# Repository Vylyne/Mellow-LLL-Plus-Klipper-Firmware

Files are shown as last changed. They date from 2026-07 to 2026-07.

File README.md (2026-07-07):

`src/buffer.c` is firmware — it gets compiled and flashed to the buffer board's own MCU (Installation Steps 0–6 below). `klippy_extras/` and `macros/` are host-side — they run as part of Klippy on your Klipper host (Pi/SBC) and only need `install.sh` (no compiling or flashing).

---

## Installation

> Done from your Klipper host (e.g. a Raspberry Pi). Commands assume `~/klipper` and `~/katapult` ([Arksine/katapult](https://github.com/Arksine/katapult)) are cloned, the Klipper build toolchain is installed, and `dfu-util` is available (`sudo apt install dfu-util`).

### Step 0 — Find your buffer & power it

Connect the buffer's USB to the host **and** give it **24 V on VIN** (the motor needs it; the firmware configures the TMC at first boot, so 24 V must be present then).

List USB serial devices to identify the board and note your **unique chip ID** (you'll reuse it in `printer.cfg`):

```bash
ls /dev/serial/by-id/
# e.g. usb-Klipper_stm32f072xb_3C003A...3720-if00   (or a Mellow / katapult id)
#                            └──────── your XXXXXX ────────┘
```

### Step 1 — Enter DFU mode (to install Katapult)

On the buffer board: **hold BOOT**, tap **RESET**, release **RESET**, then release **BOOT**. Confirm (needs `sudo`):

```bash
sudo dfu-util -l
# → Found DFU: [0483:df11] ... name="@Internal Flash  /0x08000000/064*0002Kg"
```

### Step 2 — Back up the existing firmware (recommended)

```bash
sudo dfu-util -a 0 -d 0483:df11 -U ~/lll_backup_flash.bin       -s 0x08000000:0x20000
sudo dfu-util -a 1 -d 0483:df11 -U ~/lll_backup_optionbytes.bin            # option bytes
```

### Step 3 — Build & flash Katapult (one-time bootloader)

Katapult lets you flash all **future** updates over USB without opening the case.

```bash
cd ~/katapult
make menuconfig
```

- Micro-controller Architecture: **STMicroelectronics STM32**
- Processor model: **STM32F072**
- Clock Reference: **8 MHz crystal**
- Communication interface: **USB (on PA11/PA12)**
- Application start offset: **8 KiB**
- Support bootloader entry on rapid double click of reset: **OFF** ⚠️ *(the LLL Plus has no usable reset button; leaving this ON makes the board fail to enumerate)*

```bash
make clean && make
# board still in DFU (Step 1); flash with mass-erase so no stale app remains:
sudo dfu-util -a 0 -d 0483:df11 -D out/katapult.bin -s 0x08000000:force:mass-erase:leave
```

Re-plug USB and confirm Katapult enumerates:

```bash
ls /dev/serial/by-id/
# → usb-katapult_stm32f072xb_XXXXXX-if00
```

### Step 4 — Add this firmware to Klipper

```bash
cp src/buffer.c ~/klipper/src/buffer.c
```

Add **one line** to `~/klipper/src/Makefile` (only compiled for the F072 buffer, never for your main board):

```make
src-$(CONFIG_MACH_STM32F072) += buffer.c
```

> ⚠️ This line is reverted by `git pull` on the Klipper tree — re-add it after updating Klipper. `buffer.c` itself is untracked and survives.

### Step 5 — Build Klipper

> ⚠️ `make menuconfig` overwrites `~/klipper/.config`. If you build other MCUs (your main board, toolhead…) from this same tree, **back up its config first** and restore it afterwards:
> ```bash
> cp ~/klipper/.config ~/klipper/.config.mainboard   # backup
> # ...build & flash the buffer...
> cp ~/klipper/.config.mainboard ~/klipper/.config    # restore later
> ```

```bash
cd ~/klipper
make menuconfig
```

- Micro-controller Architecture: **STMicroelectronics STM32**
- Processor model: **STM32F072**
- Bootloader offset: **8 KiB bootloader** *(must match Katapult)*
- Clock Reference: **8 MHz crystal**
- Communication interface: **USB (on PA11/PA12)**

```bash
make clean && make
```

### Step 6 — Flash Klipper over USB (via Katapult)

```bash
~/klippy-env/bin/python3 ~/katapult/scripts/flashtool.py \
  -f ~/klipper/out/klipper.bin \
  -d /dev/serial/by-id/usb-katapult_stm32f072xb_XXXXXX-if00
```

> Use the **klippy-env** Python — it has `pyserial` (the system Python usually doesn't). After flashing, the board re-enumerates as `usb-Klipper_stm32f072xb_XXXXXX-if00`.

### Step 7 — printer.cfg

```ini
[mcu LLL_PLUS]
serial: /dev/serial/by-id/usb-Klipper_stm32f072xb_XXXXXX-if00
restart_method: command

[filament_switch_sensor lll_entrance]
switch_pin: ^!LLL_PLUS:PB7
pause_on_runout: True
```

**Choosing the runout behaviour** (pick one):

- **Simplest — most setups:** `pause_on_runout: True` and nothing else. On runout Klipper runs your normal `PAUSE`, *including the park position your `[gcode_macro PAUSE]` / `[pause_resume]` already defines* (the same one your slicer pause uses). Your park position lives in your `PAUSE` macro — `pause_on_runout` calls it, so you don't repeat it here.

- **Add a notification / lights / etc.:** keep `pause_on_runout: True` and add a `runout_gcode:` — it runs **after** the pause, so use it for *extra* actions (not another pause):
```ini
  runout_gcode:
      M118 LLL Plus: filament runout — paused
  insert_gcode:
      M118 LLL Plus: filament reinserted
```

- **Fully custom routine** (your own park macro, `M600`, unload sequence…): set `pause_on_runout: False` and put your macro in `runout_gcode:`:
```ini
  pause_on_runout: False
  runout_gcode:
      MY_RUNOUT_MACRO
```

> ⚠️ Don't put a bare `PAUSE` in `runout_gcode` while `pause_on_runout: True` — it's a double pause. And `pause_on_runout`/`PAUSE` both rely on `[pause_resume]` being in your config (standard on virtually all printers).

**No motor/stepper/TMC section** — the firmware owns the motor; the host only reads `PB7`. Then `FIRMWARE_RESTART`.

### Step 8 — Host-side integration (optional)

This step adds two Klipper `extras` modules on top of the firmware above — neither is required for basic auto-feed + runout, which works fully from Step 7 alone.

```bash
./install.sh
```

This symlinks `klippy_extras/buffer_manager.py` and `klippy_extras/filament_watcher.py` into `~/klipper/klippy/extras/`, and the example config from `macros/` into `~/printer_data/config/`. Because these are symlinks, a later `git pull` on this repo updates the running modules immediately — you only need to re-run `install.sh` if new files are added to the repo, not for ordinary updates.

#### `buffer_manager` — host-commanded load/unload

Wraps `buffer_set_mode`/`buffer_query_state` from the firmware. One `[buffer_manager]` section per buffer board:

```ini
[buffer_manager LLL_PLUS]
mcu: LLL_PLUS
feed_speed_mm_s: 20.0   # measure this against your own buffer - don't derive it
                        # from the VACTUAL/RPM constants in buffer.c, since it
                        # also depends on your pulley/wheel diameter.
```

Two gcode commands become available for macros:

```gcode
BUFFER_SET_MODE BUFFER=LLL_PLUS MODE=FORWARD   ; push filament
BUFFER_SET_MODE BUFFER=LLL_PLUS MODE=BACK      ; retract filament
BUFFER_SET_MODE BUFFER=LLL_PLUS MODE=STOP      ; hold
BUFFER_SET_MODE BUFFER=LLL_PLUS MODE=AUTO      ; hand control back to the
                                                ; firmware's hall-sensor logic
BUFFER_QUERY BUFFER=LLL_PLUS                   ; report last known sensor/motor state
```

A held `FORWARD`/`BACK`/`STOP` is kept alive automatically while your macro runs (re-sent to the MCU every 250 ms); the firmware's own `timeout` watchdog means a crashed or disconnected host can't leave the motor running. Always finish a load/unload macro with `MODE=AUTO` explicitly — don't rely on the watchdog expiring as your normal hand-back path.

#### `filament_watcher` — direction-aware jam detection

Useful with any downstream motion sensor (e.g. a Mellow Fly MDM) — not specific to this buffer board, though `buffer_manager` above is one of the things it can watch for reversal-induced slack:

```ini
[filament_watcher MDM]
motion_pin: LLL_PLUS:PA5      # or wherever your MDM/encoder motion pin lives
detection_length: 3.5         # match your encoder wheel's rated segment spacing
confirm_window: 0.5           # seconds - two detections within this window before pausing

# name:backlash_mm pairs, comma separated. Each name is a printer object
# exposing get_position()/get_direction() (or find_past_position(), like
# extruder). backlash_mm is how far that source can travel after a direction
# reversal before we start counting missed-pulse distance against
# detection_length - accounts for slack/tolerance in that source's path to
# the encoder. Measure both values on your own setup; don't guess them.
position_sources: extruder:2.0, buffer_manager LLL_PLUS:5.0

# this gcode executes on first event missed motion event after grace period, intention is for logging.
warn_gcode:
    RESPOND MSG="Suspected filament clog on T0 - watching..."

runout_gcode:
    RESPOND MSG="Suspected filament clog"
    # TOOL is optional - omit it entirely on non-toolchanger setups
    _FILAMENT_JAM_DETECTED TOOL=T0
```

`confirm_window` requires two missed-pulse detections within that window before escalating to `runout_gcode` — a single stray miss just logs a warning. Both `detection_length` and every `backlash_mm` value are physical properties of your specific filament path (tube length/stiffness, encoder wheel choice, toolchanger dwell) and need measuring on your own hardware rather than copied from this example.

#### Uninstalling the host-side modules

```bash
./uninstall.sh
```

Only removes files it created as symlinks — it won't touch a real file that happens to share the name. It doesn't remove the `[include ...]` line from your `printer.cfg`, or revert the buffer board's own firmware (that's a separate flash step, see [Updating later](#updating-later-no-case-opening) in reverse — flash back a backed-up `.bin` from Step 2 if you want the board off this firmware entirely).

---

## Updating later (no case opening)

```bash
cd ~/klipper && make clean && make          # (re-add the Makefile line if a git pull removed it)
~/klippy-env/bin/python3 ~/katapult/scripts/flashtool.py \
  -f ~/klipper/out/klipper.bin \
  -d /dev/serial/by-id/usb-Klipper_stm32f072xb_XXXXXX-if00
# then FIRMWARE_RESTART
```

`flashtool` reboots the running app into Katapult over USB automatically — you can target the **Klipper** serial directly, no buttons.

The host-side modules (`klippy_extras/`, `macros/`) don't need reflashing — `git pull` in this repo updates them immediately since `install.sh` symlinks rather than copies. Run `FIRMWARE_RESTART` after pulling if either module's config or code changed.

---

## TMC2208 register values

Derived directly from Mellow's firmware parameters (via the `TMCStepper` library it uses), not guessed:

| Register | Value | Notes |
|---|---|---|
| GCONF | `0x000001C4` | spreadCycle, pdn_disable, mstep_reg_select (shaft bit set for FORWARD) |
| CHOPCONF | `0x12020055` | toff=5, vsense, 64 µsteps, intpol |
| IHOLD_IRUN | `0x00010F07` | IRUN=15, IHOLD=7 (≈ `rms_current(500)` @ Rsense 0.11) |
| PWMCONF | `0xC10D0024` | pwm_autoscale |
| VACTUAL | `77575` | 260 rpm, 64 µsteps |

Speed/current can be changed in `src/buffer.c` (`SPEED_RPM`, the register values) and re-flashed.

---

## Known behavior — Mainsail shows MCU load ~100% (false positive)

Once this firmware is running, Mainsail's **MCU Load** bar for the LLL Plus may read **~100 %**. **This is a false positive — the MCU is not overloaded.**

The autonomous auto-feed task bit-bangs the TMC2208 `VACTUAL` value over a software UART. Each update is a short, tightly-timed burst (~8 ms), which inflates the per-task timing **standard deviation** that Mainsail's load indicator is built on — even though the MCU is idle the vast majority of the time.

Measured over a full print (`klippy.log` / MCU stats):

| Metric | Value | Meaning |
|---|---|---|
| `mcu_awake` | ~0.03–0.06 | awake only **~3–6 %** of the time |
| `mcu_task_avg` | ~0.4 ms | tasks are short |
| `mcu_task_stddev` | ~2.5 ms | spikes from the bit-bang `VACTUAL` bursts (~8 ms) — this is what drives the "100 %" bar |
| `send_seq` vs `receive_seq` | equal | no command backlog |
| retransmits | a few bytes over a whole print | link healthy |
| "Timer too close" / shutdowns | **0** | no real overload |

**Conclusion:** the ~100 % reading is a display artifact of the bit-bang timing jitter, not an overloaded MCU. Auto-feed, buttons and runout all keep working normally — no action needed.

---

## Status / disclaimer

Validated on **one setup** (FLY LLL Buffer Plus, STM32F072CB).

**Bench-tested & working (firmware, `src/buffer.c`):**
- Auto-feed — hall sensors driving the motor (core state machine + `VACTUAL`).
- Manual **hold** of the feed / retract buttons (KEY1 / KEY2).
- Runout on `PB7` → print pause.

**Ported faithfully from Mellow's firmware but not individually exercised here** (no hardware/wiring to trigger them on this setup): mainboard signal control (`PB5`/`PB6`), the buttons' single-/double-click side-effects (EXT pin output, pause toggle), and the 60 s jam timeout.

**Host-side modules (`klippy_extras/buffer_manager.py`, `klippy_extras/filament_watcher.py`) are newer and not yet hardware-validated.** The host-commanded mode override and its watchdog fallback are implemented against the firmware commands above but haven't been exercised through a real load/unload cycle yet. The jam-detection backlash/grace logic depends on `detection_length`, `confirm_window`, and every `backlash_mm`/`feed_speed_mm_s` value being measured on real hardware rather than left at example defaults — treat the example config values as starting points, not calibrated numbers.

Pins and register values are specific to this board.

**⚠️ No warranty — use at your own risk.** This is experimental, community firmware provided **AS-IS, with NO WARRANTY of any kind** (see the [GPL-3.0](LICENSE) license — *Disclaimer of Warranty* §15 and *Limitation of Liability* §16). Flashing MCU firmware **can brick the board or damage hardware**. You assume **all** risk; the author accepts **no liability** for any damage, bricked board, failed/ruined print, or other loss. **Back up your existing firmware first** (Step 2) and make sure you understand each step before running it.

## Credits

- **[Fly3DTeam / Mellow](https://github.com/Fly3DTeam/Buffer)** — original FLY Buffer firmware & hardware (state machine ported from their open source).
- **[Nitrooxyde/Mellow-LLL-Plus-Klipper-Firmware](https://github.com/Nitrooxyde/Mellow-LLL-Plus-Klipper-Firmware)** — source for the autonomous smart-buffer auto-feed Klipper firmware this project builds on.
- **[Klipper](https://github.com/Klipper3d/klipper)** — MCU firmware framework.
- **[Katapult](https://github.com/Arksine/katapult)** — USB bootloader.
- Community Klipper integrations: [river29](https://github.com/river29/Mellow-LLLBufferPLUS-klipper), [ss1gohan13](https://github.com/ss1gohan13/BufferPLUS-klipper).

## License

[GPL-3.0](LICENSE) — derived from GPL-3.0 sources (Fly3DTeam/Buffer, Klipper).

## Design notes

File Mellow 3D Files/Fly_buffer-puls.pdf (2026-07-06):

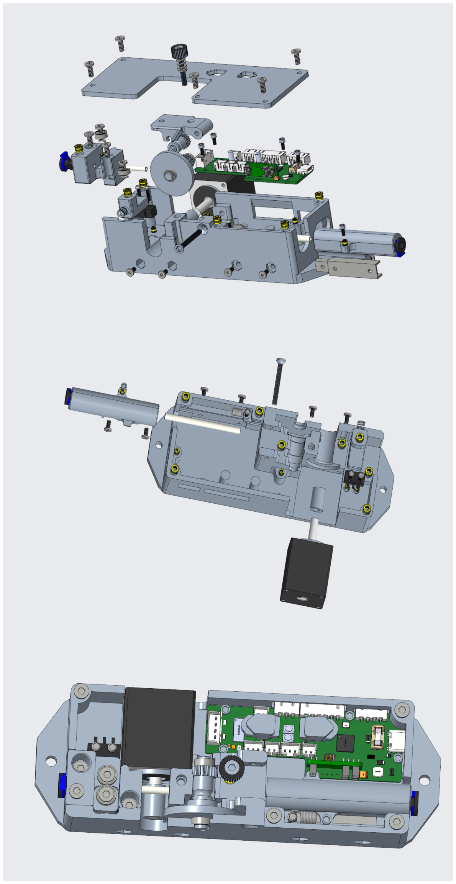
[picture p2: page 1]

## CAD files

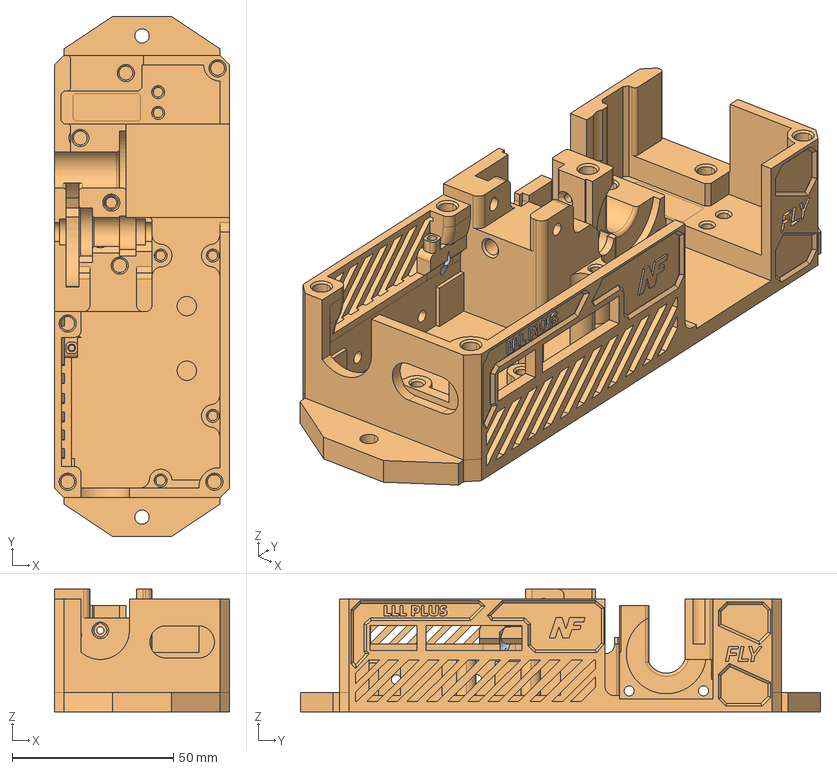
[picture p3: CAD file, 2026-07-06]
Mellow 3D Files/STEP files/Main Body.stp
54.2 x 161.0 x 38.0 mm

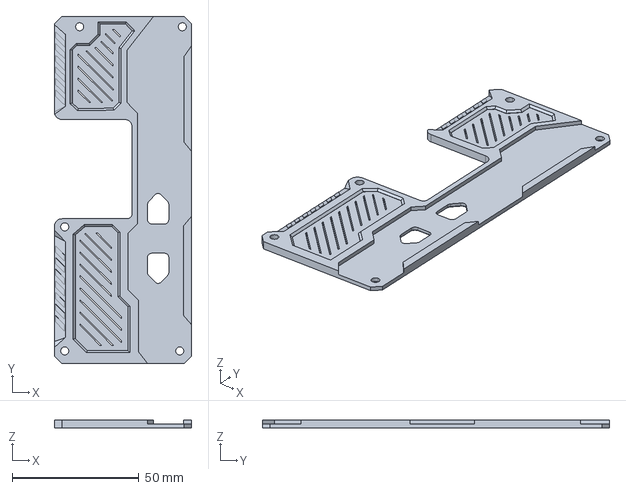
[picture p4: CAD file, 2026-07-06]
Mellow 3D Files/STEP files/Main Cover.stp
54.2 x 137.0 x 3.03 mm

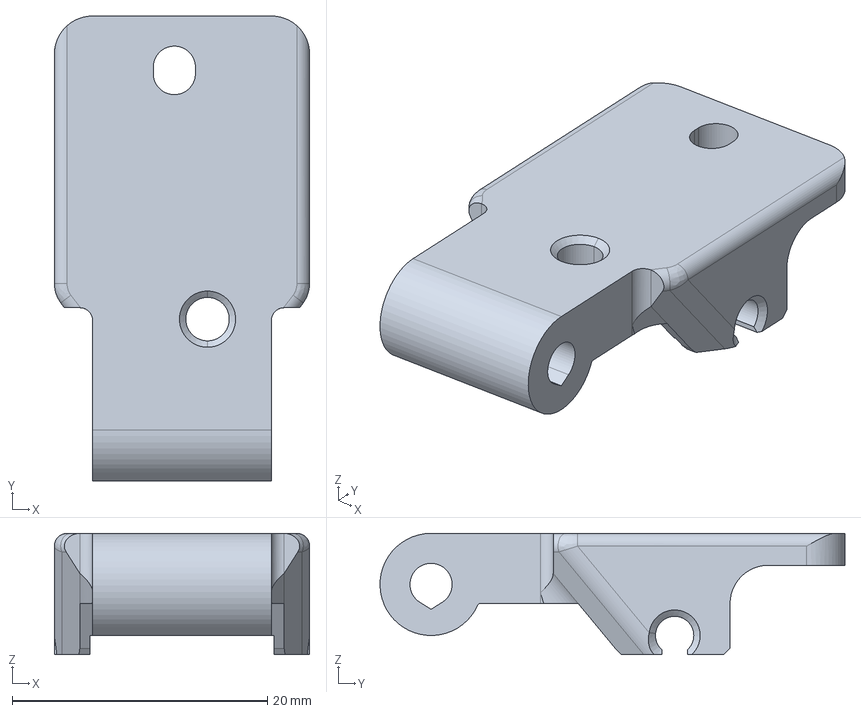
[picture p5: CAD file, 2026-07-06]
Mellow 3D Files/STEP files/Idler Tensioner.stp
20.0 x 36.4 x 9.50 mm

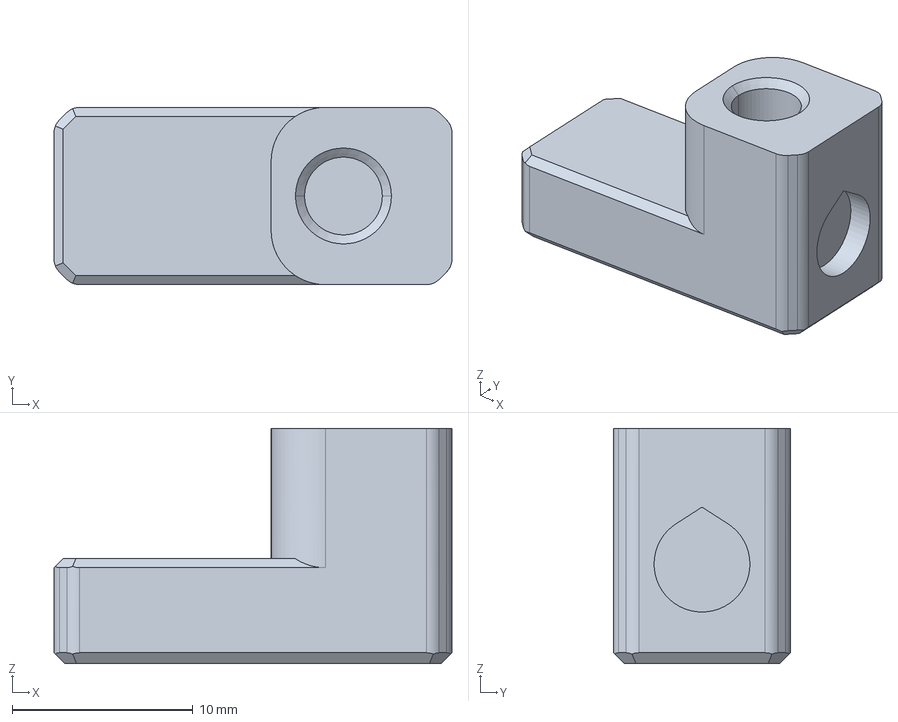
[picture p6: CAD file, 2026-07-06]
Mellow 3D Files/STEP files/Enterance Swtich Lever.stp
22.0 x 9.80 x 13.0 mm

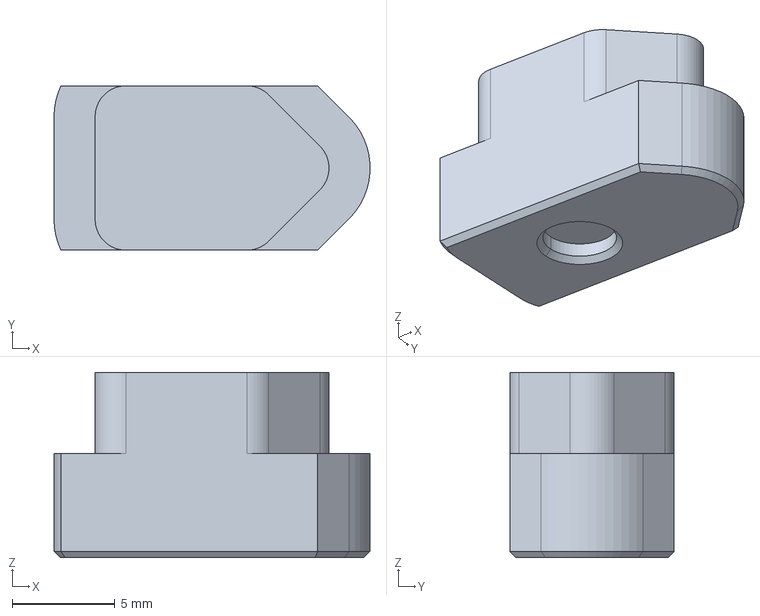
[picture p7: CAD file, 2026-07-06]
Mellow 3D Files/STEP files/Button.x2.stp
15.4 x 8.00 x 9.00 mm

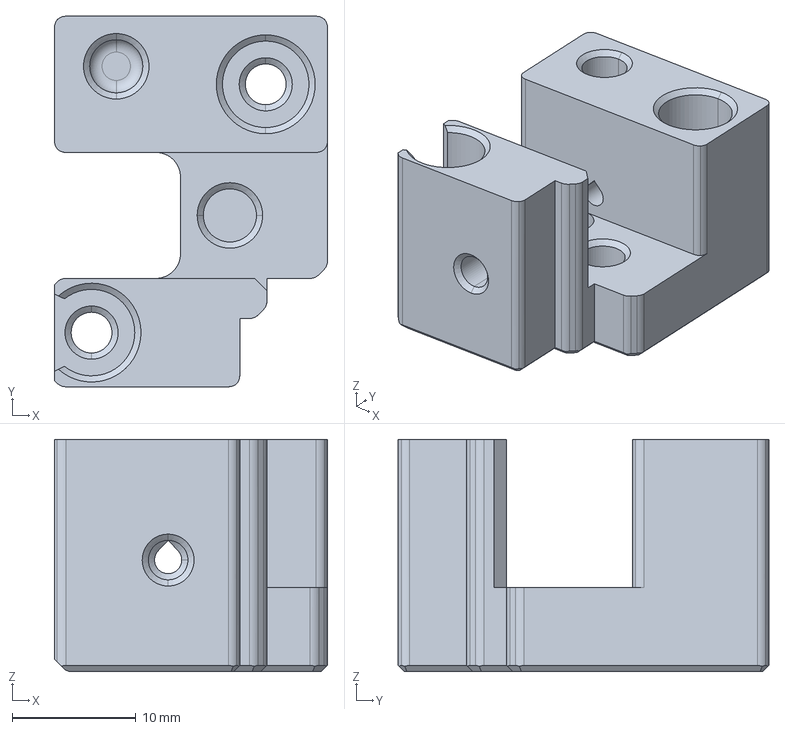
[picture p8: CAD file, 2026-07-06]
Mellow 3D Files/STEP files/Enterance Block.stp
22.1 x 30.0 x 18.8 mm

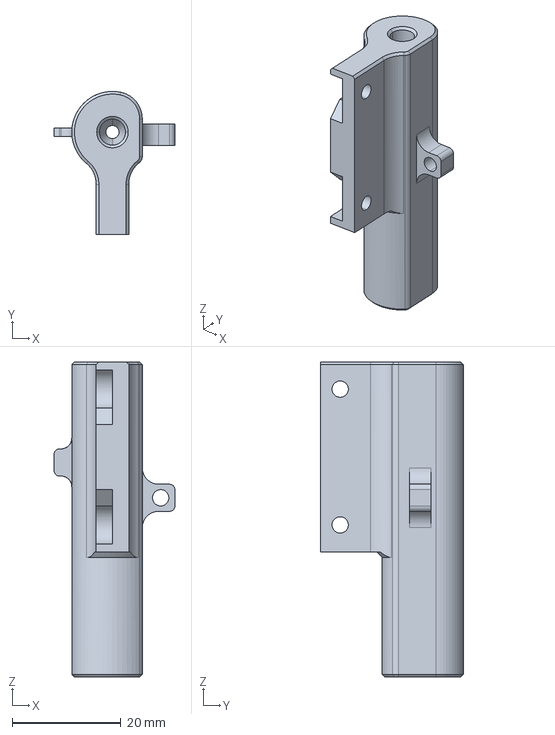
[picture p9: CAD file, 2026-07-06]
Mellow 3D Files/STEP files/Buffer Tube (slider).stp
22.2 x 26.4 x 58.0 mm

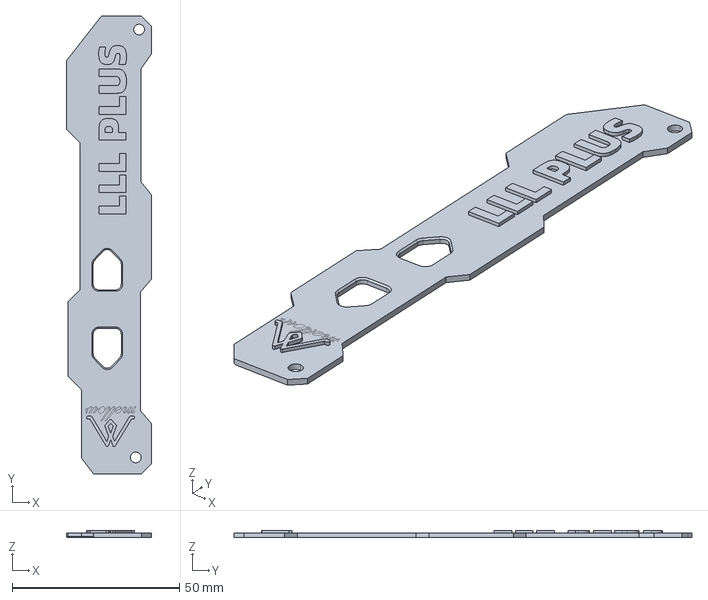
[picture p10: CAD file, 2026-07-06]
Mellow 3D Files/STEP files/Colour Plate.stp
25.4 x 137.0 x 2.17 mm

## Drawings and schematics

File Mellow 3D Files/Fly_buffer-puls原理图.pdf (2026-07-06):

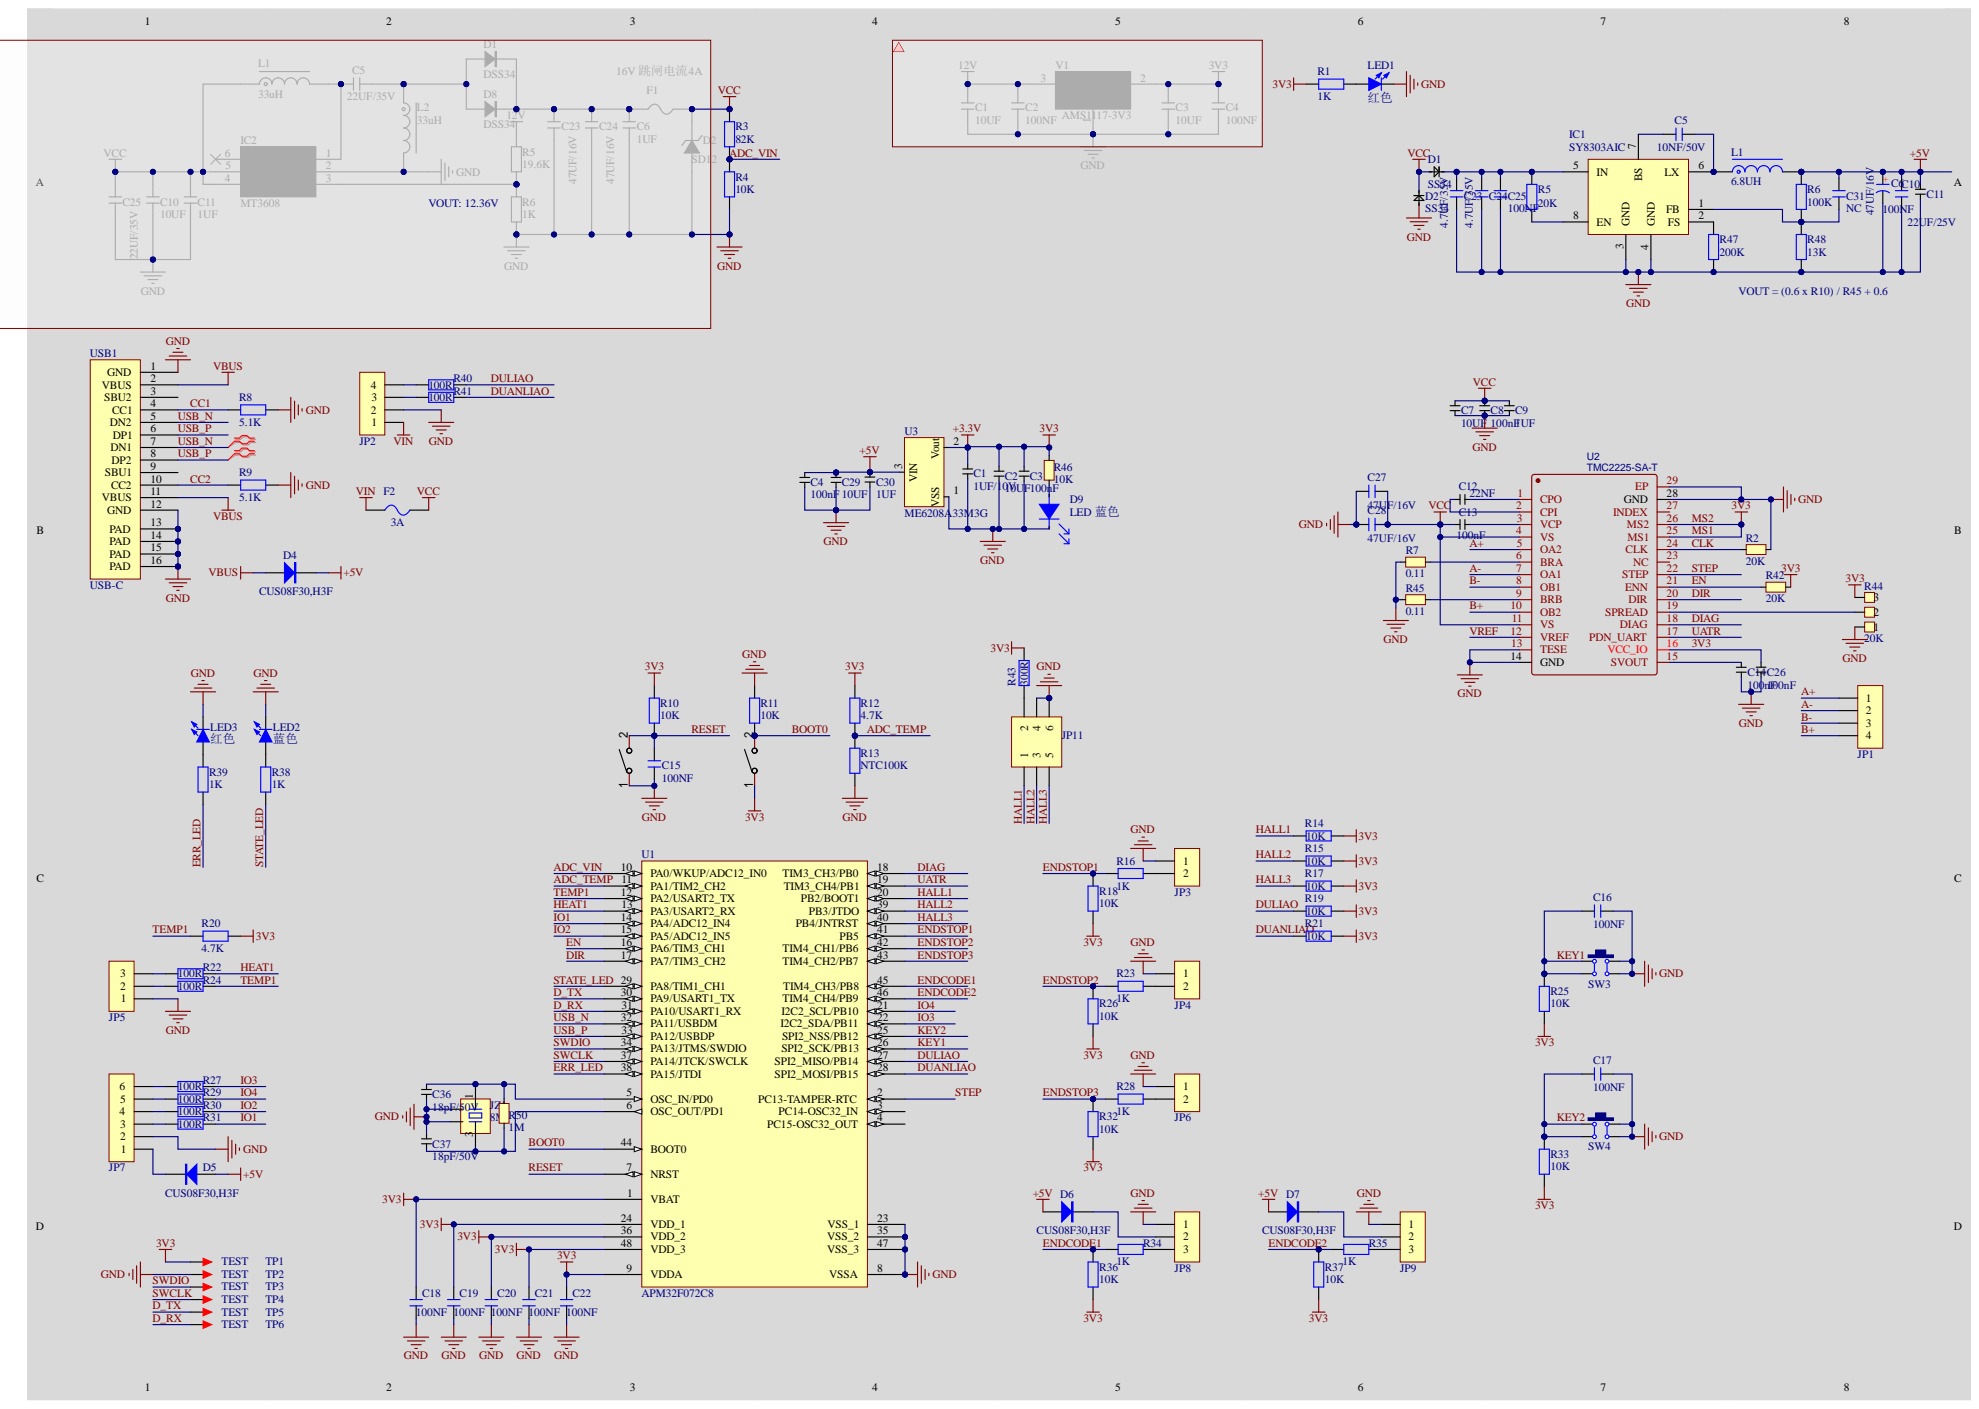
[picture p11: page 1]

VDD_1 24
VDD_2 36
VDD_3 48

VDDA 9

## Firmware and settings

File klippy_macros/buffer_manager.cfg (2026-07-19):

[gcode_macro LOAD_FILAMENT]
gcode:
    {% set tool = params.TOOL|default("T" ~ printer.toolchanger.tool_number)|upper %}
    {% set buffer = namespace(name="") %}
    {% for key in printer %}
        {% if key.startswith("buffer_manager ") %}
            {% if "T" ~ printer[key].tool == tool %}
                {% set buffer.name = key %}
            {% endif %}
        {% endif %}
    {% endfor %}
    {% if not buffer.name %}
        { action_raise_error("LOAD_FILAMENT: unknown tool '%s' (no %s)" % (tool, buffer.name)) }
    {% endif %}
    BUFFER_LOAD BUFFER={buffer.name.removeprefix("buffer_manager ").strip()} TIMEOUT=60000
    _BUFFER_JOB_POLL TOOL={tool} BUFFER={buffer.name} JOB=LOAD

[gcode_macro UNLOAD_FILAMENT]
gcode:
    {% set tool = params.TOOL|default("T" ~ printer.toolchanger.tool_number)|upper %}
    {% set buffer = namespace(name="") %}
    {% for key in printer %}
        {% if key.startswith("buffer_manager ") %}
            {% if "T" ~ printer[key].tool == tool %}
                {% set buffer.name = key %}
            {% endif %}
        {% endif %}
    {% endfor %}
    {% if not buffer.name %}
        { action_raise_error("UNLOAD_FILAMENT: unknown tool '%s' (no %s)" % (tool, buffer.name)) }
    {% endif %}
    BUFFER_UNLOAD BUFFER={buffer.name.removeprefix("buffer_manager ").strip()} TIMEOUT=60000
    _BUFFER_JOB_POLL TOOL={tool} BUFFER={buffer.name} JOB=UNLOAD

[gcode_macro _BUFFER_JOB_POLL]
gcode:
    {% set tool = params.TOOL %}
    {% set job = params.JOB %}
    {% set buffer = printer[params.BUFFER] %}
    {% if buffer.job_pending %}
        G4 P250
        _BUFFER_JOB_POLL TOOL={tool} BUFFER={params.BUFFER} JOB={job}
    {% else %}
        _BUFFER_JOB_RESULT TOOL={tool} JOB={job} STATUS={buffer.last_result_status}
    {% endif %}

[gcode_macro _BUFFER_JOB_RESULT]
gcode:
    {% set tool = params.TOOL %}
    {% set job = params.JOB %}
    {% set status = params.STATUS|int %}
    {% set labels = {0: "OK", 1: "STALLED", 2: "TIMEOUT", 3: "INTERRUPTED"} %}
    {% set label = labels.get(status, "UNKNOWN") %}
    {% if status == 0 %}
        RESPOND MSG="{job} complete: {tool}"
        # TODO: KNOMI success indication - stub. Wire up once KNOMI_CMD
        # gains a per-tool "job complete" state, e.g.:
        #   KNOMI_CMD:{tool} JOB_OK
    {% else %}
        RESPOND MSG="{job} FAILED on {tool}: {label}"
        # TODO: KNOMI failure indication - stub. Wire up once KNOMI_CMD
        # gains a per-tool "job failed" state, e.g.:
        #   KNOMI_CMD:{tool} JOB_FAIL REASON={label}
    {% endif %}

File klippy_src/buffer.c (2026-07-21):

// LLL Buffer Plus - autonomous auto-feed task for Klipper MCU firmware
//
// Ports the state machine from Mellow's standalone firmware
// (Fly3DTeam/Buffer, lib/buffer/buffer.cpp) INTO Klipper MCU firmware, as
// an autonomous task. The board remains a normal Klipper MCU (the host
// reads PB7 via [filament_switch_sensor]) AND drives the buffer motor on
// its own.
//
// ADDED file (does not modify any existing Klipper file) -> survives git pull.
//
// Convention taken VERBATIM from buffer.cpp / buffer.h:
//   photo sensor: obstructed = 1, not obstructed = 0 (direct GPIO readback, NO inversion!)
//   endstop_3/filament switch (PB7): Normally Closed, Filament Present = 0, No Filament = 1
//   buttons: normally closed, pressed = 0, released = 1
//   HALL3 (PB4) obstructed -> Forward (feed)   [pos1]
//   HALL2 (PB3) obstructed -> Stop             [pos2]
//   HALL1 (PB2) obstructed -> Back (retract)   [pos3]
//
// ONLY change vs. the standalone: button hold is handled event-driven
// (non-blocking) instead of the original blocking while() loop, because
// blocking for seconds would break Klipper host comms. Behavior is
// otherwise identical.
//
// This file may be distributed under the terms of the GNU GPLv3 license.

#include "autoconf.h"   // CONFIG_CLOCK_FREQ
#include "board/gpio.h" // gpio_in_setup / gpio_out_setup
#include "board/misc.h" // timer_read_time
#include "command.h"    // DECL_COMMAND / sendf
#include "sched.h"      // DECL_TASK / DECL_INIT

// ------------------------------------------------------------------
// Pins (Klipper encoding: GPIO(PORT,NUM) = (PORT-'A')*16 + NUM)
// ------------------------------------------------------------------
#define GPIO(PORT, NUM) (((PORT) - 'A') * 16 + (NUM))

#define HALL1_PIN GPIO('B', 2)             // Optical sensor 3 -> pos3 -> back limit, retract.
#define HALL2_PIN GPIO('B', 3)             // Optical sensor 2 -> pos2 -> mid, don't push or pull.
#define HALL3_PIN GPIO('B', 4)             // Optical sensor 1 -> pos1 -> forward limit, feed.
#define FIL_PIN GPIO('B', 7)               // ENDSTOP_3 / filament entry switch.
#define KEY_INTERNAL_RETRACT GPIO('B', 13) // KEY1 Retract (retract)
#define KEY_INTERNAL_FEED GPIO('B', 12)    // KEY2 Feed (feed)
#define KEY_EXTERNAL_RETRACT GPIO('A', 2)  // Exposed 3 pin header, external retract button
#define KEY_EXTERNAL_FEED GPIO('A', 3)     // Exposed 3 pin header, external feed button
#define KEY_EXTERNAL_UNLOAD GPIO('B', 10)  // Exposed 3 pin header, triggers UNLOAD job
#define KEY_EXTERNAL_LOAD GPIO('B', 11)    // Exposed 3 pin header, triggers LOAD job
#define MDM_FILAMENT_PIN GPIO('A', 4)      // MDM filament presence sensor
#define MDM_MOTION_PIN GPIO('A', 5)        // MDM motion sensor (encoder pulse)
#define FRONT_SIG_PIN GPIO('B', 5)         // mainboard "advance" signal (active low)
#define BACK_SIG_PIN GPIO('B', 6)          // mainboard "retract" signal (active low)
#define EXT1_PIN GPIO('C', 13)             // EXTENSION_PIN1
#define EXT2_PIN GPIO('C', 14)             // EXTENSION_PIN2
#define EN_PIN GPIO('A', 6)                // TMC enable (active low)
#define UART_PIN GPIO('B', 1)              // TMC2208 single-wire UART (PDN_UART)

// ASSUMPTION - VERIFY ON REAL HARDWARE: MDM_FILAMENT_PIN's raw read value
// meaning "no filament present". Your printer.cfg's
// [filament_switch_sensor T0_mdm_filament] uses a plain `^T0_buffer:PA4`
// (no `!` inversion) unlike the entrance switch's `^!`. This constant must
#define MDM_FIL_NO_FILAMENT_STATE 1

// ------------------------------------------------------------------
// Parameters (copied from standalone firmware)
// ------------------------------------------------------------------
// VACTUAL = SPEED * microsteps * 200 / 60 / 0.715   (buffer.cpp)
//   SPEED = 260 rpm, microsteps = 64 -> 77575 (matches the standalone's int cast)
#define SPEED_RPM 260
#define MICROSTEPS_DIV 64
#define VACTUAL_MAG ((int32_t)((int64_t)SPEED_RPM * MICROSTEPS_DIV * 200 / 60 * 1000 / 715))

#define FEED_TIMEOUT_MS 60000 // safety: stop if continuous FORWARD > 60s (buffer.cpp)

// ms -> MCU clock ticks conversion
#define MS_TICKS(ms) ((uint32_t)(ms) * (CONFIG_CLOCK_FREQ / 1000))

// Bit-bang UART: 9600 baud (matches the standalone's beginSerial(9600))
#define UART_BAUD 9600
#define BIT_TICKS (CONFIG_CLOCK_FREQ / UART_BAUD) // 48e6/9600 = 5000 ticks/bit

// ------------------------------------------------------------------
// TMC2208 registers (datasheet addresses) + values (DERIVED from TMCStepper)
// ------------------------------------------------------------------
#define TMC_GCONF 0x00
#define TMC_IHOLD_IRUN 0x10
#define TMC_VACTUAL 0x22
#define TMC_CHOPCONF 0x6C
#define TMC_PWMCONF 0x70
#define TMC_WRITE_FLAG 0x80
#define TMC_SLAVE_ADDR 0x00 // DRIVER_ADDRESS 0b00 (buffer.h)
#define TMC_SYNC 0x05

#define GCONF_VAL 0x000001C4UL      // i_scale_analog=0,spreadcycle,pdn_disable,mstep_reg_select,multistep_filt
#define GCONF_SHAFT 0x00000008UL    // bit3 shaft (FORWARD=1)
#define CHOPCONF_VAL 0x12020055UL   // toff=5,vsense=1,mres=2(64u),intpol=1
#define IHOLD_IRUN_VAL 0x00010F07UL // IHOLD=7,IRUN=15,iholddelay=1 (rms_current(500)@0.11)
#define PWMCONF_VAL 0xC10D0024UL    // TMC2208 default (pwm_autoscale)

// ------------------------------------------------------------------
// Motor state
// ------------------------------------------------------------------
enum
{
    ST_STOP = 0,
    ST_FORWARD,
    ST_BACK
};

// Hall / optical position sensors (buffer dancer arm)
static struct gpio_in hall1, hall2, hall3;

// Filament presence (entrance)
static struct gpio_in fil;

// Physical buttons - board-mounted
static struct gpio_in key_internal_retract, key_internal_feed;

// Physical buttons - external header
static struct gpio_in key_external_retract, key_external_feed;
static struct gpio_in key_external_load, key_external_unload;

// Mainboard control signals
static struct gpio_in front_sig, back_sig;

// MDM (downstream encoder module)
static struct gpio_in mdm_filament, mdm_motion;

static struct gpio_out en_out, uart_out, ext1, ext2;
static uint8_t last_state = ST_STOP;
static uint8_t tmc_ready = 0;
static uint32_t feed_start_time;
static uint8_t is_feeding = 0;
static uint8_t is_error = 0;

// Button state (replaces the standalone's attachInterrupt with polling)
static uint8_t key1_prev = 1, key2_prev = 1;
static uint32_t key1_press_t, key2_press_t, key1_rel_t, key2_rel_t;
static uint8_t key1_held = 0, key2_held = 0;
static uint8_t key1_rel = 0, key2_rel = 0;
static uint8_t key1_cnt = 0, key2_cnt = 0;
static uint8_t manual = 0; // 0=none, 1=forward, 2=back
static uint8_t inform = 0;
static uint32_t inform_t;

// ------------------------------------------------------------------
// Load/unload job state
// ------------------------------------------------------------------
enum
{
    JOB_NONE = 0,
    JOB_LOAD,
    JOB_UNLOAD
};
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

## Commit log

2026-05-24 Klipper MCU firmware for Mellow FLY LLL Buffer Plus (autonomous auto-feed + Klipper runout)
2026-05-24 README: full step-by-step (find USB device, enter DFU, dfu-util, Katapult, build, flash)
2026-05-24 README: warn to back up ~/klipper/.config before menuconfig (avoids clobbering main board config)
2026-06-25 moved ext_1 and ext_2 to unused pins and added external button inputs pn PA2 and PA3 instead.
2026-07-06 feat: add FilamentWatcher class for monitoring filament runout
2026-07-06 feat: add install script for creating symbolic link to filament_motion_watcher.py
2026-07-06 Added Mellow 3d's Filament LLL Plus Buffer Files
    [Buffer Tube (slider).stp, Button.x2.stp, Colour Plate.stp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]
2026-07-06 feat: add filament jam detection and pause macros
    [filament_watcher.cfg]
2026-07-06 feat: enhance filament jam detection with improved confirmation logic and template integration
    [filament_watcher.cfg]
2026-07-06 Renamed extras folder to klippy_extras for clarity
    [filament_watcher.cfg]
2026-07-06 updated macros to allow for no toolchanger..
    [filament_watcher.cfg]
2026-07-06 fix: correct message formatting for filament jam pause response
    [filament_watcher.cfg]
2026-07-06 fix: correct punctuation in filament jam pause response message
    [filament_watcher.cfg]
2026-07-06 FIX: check for klipper src dir.
2026-07-06 FIX: correct check for KLIPPER_SRC to verify directory existence
2026-07-06 FIX: include command.h for buffer state query and improve formatting in buffer_task
    [buffer.c]
2026-07-07 FIX: update response registration to follow current klipper signature
2026-07-07 FIX: add enable/disable functionality for filament sensor and update status reporting
2026-07-07 FIX: add filament sensor registration and enable configuration
2026-07-07 FIX: remove unused jam_pending_since attribute from FilamentWatcher
2026-07-14 FIX: enhance BufferManager to track hall sensor stuck states and improve status reporting
    [buffer.c]
2026-07-14 FIX: remove placeholder comment for stall_seconds in BufferManager initialization
2026-07-18 FIX: remove commented warn output in _warn method of FilamentWatcher
2026-07-19 refactor/rewrite to move resource load to buffer mcu instead of klipper host.
2026-07-19 refactor: replace filament_watcher with buffer_manager and update related configurations
    [buffer_manager.cfg, filament_watcher.cfg]
2026-07-19 refactor: remove filament_watcher references from install and uninstall scripts
2026-07-19 refactor: update BufferManager to handle post-extruder sensor events and clean up toolhead sensor logic
2026-07-21 refactor: reverted SPEED_RPM to match standalone firmware settings
    [buffer.c]
